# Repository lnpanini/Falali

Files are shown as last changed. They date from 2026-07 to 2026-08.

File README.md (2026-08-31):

# Falali — a 30.007 project

An AMR-style **under-ride platform** that drives beneath a textile trolley, uses upward-facing
time-of-flight sensors to confirm it is under the trolley and centred, **clamps** onto the
underside, and then moves the trolley. ESP32-S3 firmware, hardware and documentation.

This is also the whole-project home for **Falali — One AMR Fits All** (SUTD 30.007 Engineering
Design Innovation, Group 10): a low-profile autonomous mobile robot that moves existing fabric
trolleys in a textile factory by driving *underneath* them, clamping on, and transporting them —
no changes to the trolleys or the factory floor.

- **Controller:** ESP32-S3-WROOM-1 **N16R8** (16 MB flash, 8 MB octal PSRAM)
- **No** LiDAR, camera, ROS 2, SLAM, or mapping.

> **Hardware documentation lives in [`docs/hardware/`](docs/hardware/)** — power-up runbook,
> component list, per-connector pinouts for all three PCBs (extracted from the KiCad netlists, not
> inferred), and a fabrication/repair guide. [`docs/hardware-architecture.md`](docs/hardware-architecture.md)
> is the older companion and is partly superseded by it. The pin table further down this README is
> the *pre-PCB design intent* and does **not** match the fabricated board.

Full design: [`docs/superpowers/specs/2026-07-06-falali-esp32-docking-design.md`](docs/superpowers/specs/2026-07-06-falali-esp32-docking-design.md).

## Results against requirements

| Requirement | Target | Result |
|---|---|---|
| Fit under trolley clearance | ≤ 200 mm | **167 mm**, validated on the physical chassis |
| Move loaded trolley | ≥ 100 kg | **Passed — load moved with two people standing on top** |
| Clamp holding force | ≥ 300 N | Weakest-link analysis: clamp capacity 403 N (SF 1.34×) |
| Clamp vertical reach | ≥ 200 mm | Met |
| Docking time | ≤ 1 min | Under 60 s in testing |
| Worst-case castor misalignment | All 4 orientations | Moves under all |

Derivations, test protocols and data: [`docs/pdr-falali-amr.pdf`](docs/pdr-falali-amr.pdf)
(Preliminary Design Review deck, 11 Aug 2026).

## Delivered system

```
ESP-BASE (Wheel Drive PCB)                  ESP-ARM (Arm Subsystem PCB)
docking state machine                       arm axes X/Y, flipper servos, clamp
mecanum mixing, 4× corner ToF centring   ⇄  limit switches, homing
clamp handoff                             ESP-NOW over Wi-Fi (channel 1)

operator: BLE gamepad ([bench_ble/](bench_ble/))
```

Commercial AMRs don't fit this job: platform AMRs are too tall to get under the trolleys, tow
tractors need turning space, side-docking systems need the trolley modified. The answer is
**under-entry capture**: fit under the ≤200 mm clearance, strafe beneath an existing trolley with
mecanum drive, confirm centring sensor-only, clamp and carry.

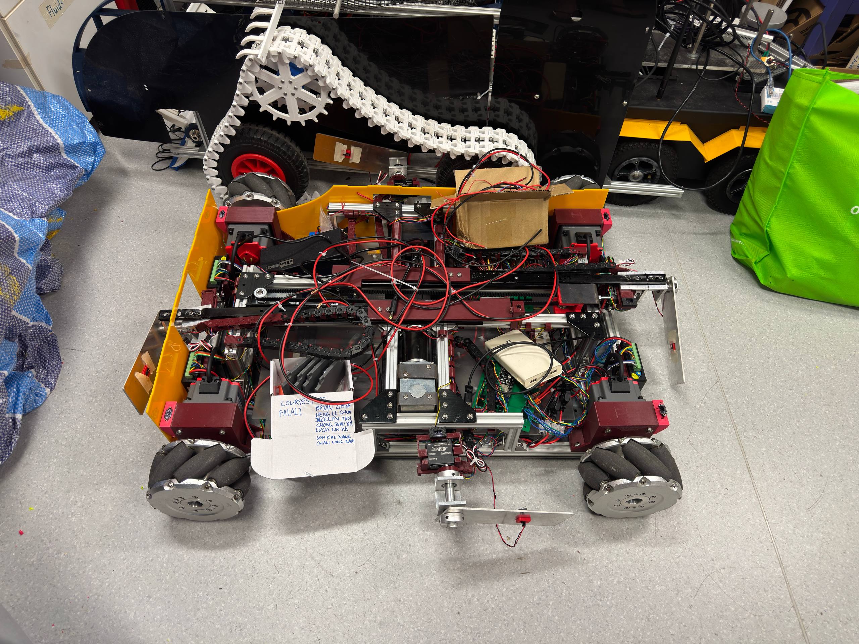
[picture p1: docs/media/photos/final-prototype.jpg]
Falali final prototype


## Safety principle

**The clamp must not engage unless the alignment logic CONFIRMS the platform is centred.** Limit
switches only confirm clamp *travel*; they never authorise clamping. `SafetyMonitor` is the single
gate (`confirmed && no faults && !E-stop`), and the docking state machine reaches the clamp handoff
only after a sustained `CONFIRM`. The clamp/arm mechanism itself is an **external subsystem** that
plugs in at the `IClamp` port.

## Architecture — hexagonal (ports & adapters)

```
lib/ports      pure C++ interfaces + shared types (no Arduino)
lib/domain     the hand-written core:  CornerEdgeDetector · DeadReckonOdometry · SafetyMonitor · DockingStateMachine
lib/drive      MecanumDrive (mixes body-frame vx/vy/omega -> 4 wheels)
lib/fakes      desktop test doubles for every port
lib/hal_esp32  Arduino adapters over popular libraries
include/       config.h (tunables) · pins.h (GPIO map)
src/main.cpp   composition root: builds adapters, wires domain, runs the loop
test/          host unit tests (Unity)
```

Dependency rule: **domain → ports** only; **adapters → ports**; **main → everything**. The domain
never includes Arduino, so it compiles and tests on a laptop. Commodity work uses popular libraries
(`pololu/VL53L0X`, `Bounce2`, `ArduinoJson`, `SerialCommands`, ESP32 `LEDC`); only the docking
sequence, corner edge detection, odometry, and safety logic are hand-written — and that is the part
under test.

**Alignment method:** with a solid trolley board and 4 corner ToF sensors, docking is a deterministic
geometric sequence — `APPROACH → ORIENT` (rotate until both front corners see the edge) `→ CENTER_X`
(odometry-centre between near/far edges) `→ CENTER_Y` (same, strafing) `→ CONFIRM → clamp handoff`.
Centring uses dead-reckoning odometry; driving to the midpoint between two edge events makes it robust
to calibration error.

**ToF wiring, both ESPs:** all four corner sensors keep their factory address `0x29` and are brought
up one at a time via **XSHUT re-addressing** — `Vl53l0xArray` on the base, `TofSensorArray` in
`arm/`. An earlier design multiplexed them through the PCA9548A breakout in
[`KiCad/PCA9548A Breakout/`](KiCad/PCA9548A%20Breakout/); final firmware uses no mux, and the
breakout is kept as history of that era.

## Build, test, flash

```bash
# Host unit tests of the pure core — no hardware needed:
pio test -e native

# Compile / upload the firmware (fetches lib_deps):
pio run -e esp32s3
pio run -e esp32s3 -t upload
pio device monitor -b 115200
```

Arm subsystem firmware has its own project: [`arm/`](arm/README.md).

## Operator interface — Xbox gamepad over BLE

**The robot is driven from a gamepad, not a serial console.** `bench_ble/` runs
Bluepad32, which owns stdin: `Console` is output-only and `Serial` is never
`begin()`-ed, so **typed commands cannot reach the firmware.** Every operator
control is a gamepad button. See [`docs/gotchas.md`](docs/gotchas.md) §6.

The base prints status to the console as it runs; that is one-way.

> A `DOCK`/`ABORT`/`UNCLAMP`/`STATUS` serial protocol was designed and the
> parser written, but it never ran on hardware — see **Project history** below.

## Pin map — ESP32-S3-N16R8

> ## 🛑 The table below is WRONG. Do not wire or flash from it.
>
> It is the **pre-PCB design intent** and does not match the fabricated board. On the real board
> GPIO4–7 are the **ToF XSHUT** lines, not wheel SV, and GPIO38/39 are **motor brake** lines, not
> I²C. Using this map would drive the I²C bus as motor enables.
>
> **The real map is [`include/pins.h`](include/pins.h)**, extracted from the KiCad netlist, with
> per-connector pinouts in [`docs/hardware/boards.md`](docs/hardware/boards.md).
>
> Kept here only because it is referenced by older notes. It should be deleted.

Reserved on the N16R8: **GPIO26–37** (flash + octal PSRAM) and **GPIO19/20** (USB-CDC).

| Group | Signals | GPIO |
|---|---|---|
| Wheel speed (SV, PWM) | FL/FR/RL/RR | 4, 5, 6, 7 |
| Wheel direction (F/R) | FL/FR/RL/RR | 15, 16, 17, 18 |
| Wheel enable / brake (ganged) | EN / BRK | 8 / 9 |
| Clamp (BTS7960) | RPWM / LPWM / EN | 11 / 12 / 13 |
| Clamp current sense (ADC1) | IS close / open | 1 / 2 |
| Limit switches | open / closed | 14 / 21 |
| ToF I²C | SDA / SCL | 38 / 39 |

## Hardware bring-up checklist (before trusting it under a trolley)

These adapters were validated on the assembled robot over the 2026 term. Kept as
a bring-up order for a rebuild, or after a board respin:

1. **PWM API** — a `PwmPin` shim supports Arduino-ESP32 core 2.x *and* 3.x automatically.
2. **BLD120A polarities** — `F/R` forward sense, and active-low `EN`/`BRK` (`Bld120aMotor.h`). There
   is no `ALARM`: the driver has no such terminal, only a front-panel LED.
3. **Mecanum + orient signs** — confirm forward / strafe / yaw directions (`MecanumDrive.cpp`) and the
   `ORIENT` rotate-direction sign in `DockingStateMachine.cpp` (rotate toward the lagging corner).
4. **ToF corners** — FL/FR/RL/RR on their XSHUT pins (`pins::kTofXSHUT`; `Vl53l0xArray` is the
   default backend since the mux approach was retired); set the board
   **height band** (`makeCornerConfig`).
5. **Odometry calibration** — measure `max_lin_mm_s` / `max_ang_rad_s` (`makeOdometryCal`); tune the
   centring tolerance/offsets in `makeDockConfig`.
6. **Per-wheel current sense** — calibrate `cfg::kWheelStallAmps` under a loaded trolley. Note the
   ACS758 outputs are **not currently wired** to J9/J12/J14/J17, so this reads nothing until they are
   ([`docs/hardware/components.md`](docs/hardware/components.md) §4). The clamp is on the *arm* board,
   not this one.
7. **Dry-run the alignment** and watch the JSON telemetry (`corners`, `x_mm`, `y_mm`, `confirmed`). The
   clamp/arm subsystem is external and validated separately at the `IClamp` handoff.

## Custom PCBs

Connector-level references for all boards (every pin extracted from the KiCad netlists):
[`docs/hardware/boards.md`](docs/hardware/boards.md).

| Board | Size | KiCad project | Job |
|---|---|---|---|
| **Wheel Drive PCB** | 130 × 105 mm | [`KiCad/Wheel Drive PCB/`](KiCad/Wheel%20Drive%20PCB/) | base ESP + 4 motor-driver adapters + all base sensors |
| **Driver PCB** ×4 | 42.8 × 33.8 mm | [`KiCad/Driver PCB/`](KiCad/Driver%20PCB/) | 3.3 V → open-collector adapter, one per motor |
| **Arm Subsystem PCB** | 110 × 110 mm | [`KiCad/Arm Subsystem PCB/`](KiCad/Arm%20Subsystem%20PCB/) | arm ESP + 2 H-bridges + servos + 8 limit switches |
| PCA9548A breakout | — | [`KiCad/PCA9548A Breakout/`](KiCad/PCA9548A%20Breakout/) | I²C mux — **historical**, see ToF note above |

JLCPCB fab outputs ship with each project (`fab-output/` folders; the Arm board's zip is in its
folder). Board designs by Kai Xiang & Heng Li (arm/wheel sensor side) and Bryan Lim (base).

## Demos

| | |
|---|---|
| <video src="docs/media/videos/load-test-100kg.mp4" controls width="320"> | **Load test** — ≥100 kg requirement load, two people on top |
| <video src="docs/media/videos/wheel-subsystem-driving.mp4" controls width="320"> | Mecanum base driving and strafing |
| <video src="docs/media/videos/arm-subsystem-demo.mp4" controls width="320"> | Arm extension / flipper / release sequence |
| <video src="docs/media/videos/clamped-on-trolley.mp4" controls width="320"> | Clamped onto a trolley |

*(GitHub renders `<video>` tags in markdown; if your viewer doesn't, open the files under
[`docs/media/videos/`](docs/media/videos/).)*

<details>
<summary>All clips kept in the repo</summary>

| File | What it shows |
|---|---|
| [`trolley-carry-demo.mp4`](docs/media/videos/trolley-carry-demo.mp4) | full trolley-carry run (1:49) |
| [`clamping-on-sequence.mp4`](docs/media/videos/clamping-on-sequence.mp4) | clamp engaging under the trolley (0:56) |
| [`rail-strength-test.mp4`](docs/media/videos/rail-strength-test.mp4) | rail strength durability test (0:29) |
| [`img-3340.mp4`](docs/media/videos/img-3340.mp4) | bench footage (0:51) |
| [`img-3350.mp4`](docs/media/videos/img-3350.mp4) | bench footage (0:43) |
| [`video-2026-07-13.mp4`](docs/media/videos/video-2026-07-13.mp4) | mid-build progress clip (0:16) |
| [`video-2026-07-17.mp4`](docs/media/videos/video-2026-07-17.mp4) | mid-build progress clip (0:10) |
| [`clip-20260707.mp4`](docs/media/videos/clip-20260707.mp4) | early drive test (0:05) |

</details>

### Function diagrams

| System flow | Arm subsystem |
|---|---|
| System flow function diagram | Arm subsystem function diagram |

*(SVGs render inline above; click through for the higher-resolution PNGs.)*

<details>
<summary>More photos</summary>

| | | |
|---|---|---|
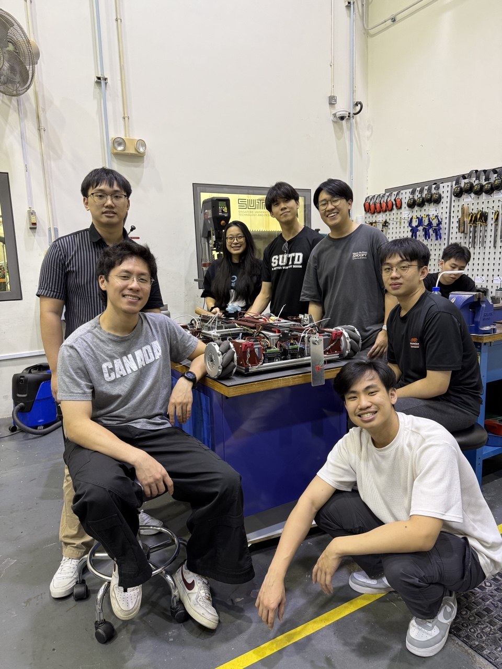
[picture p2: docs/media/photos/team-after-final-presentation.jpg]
Team after final presentation
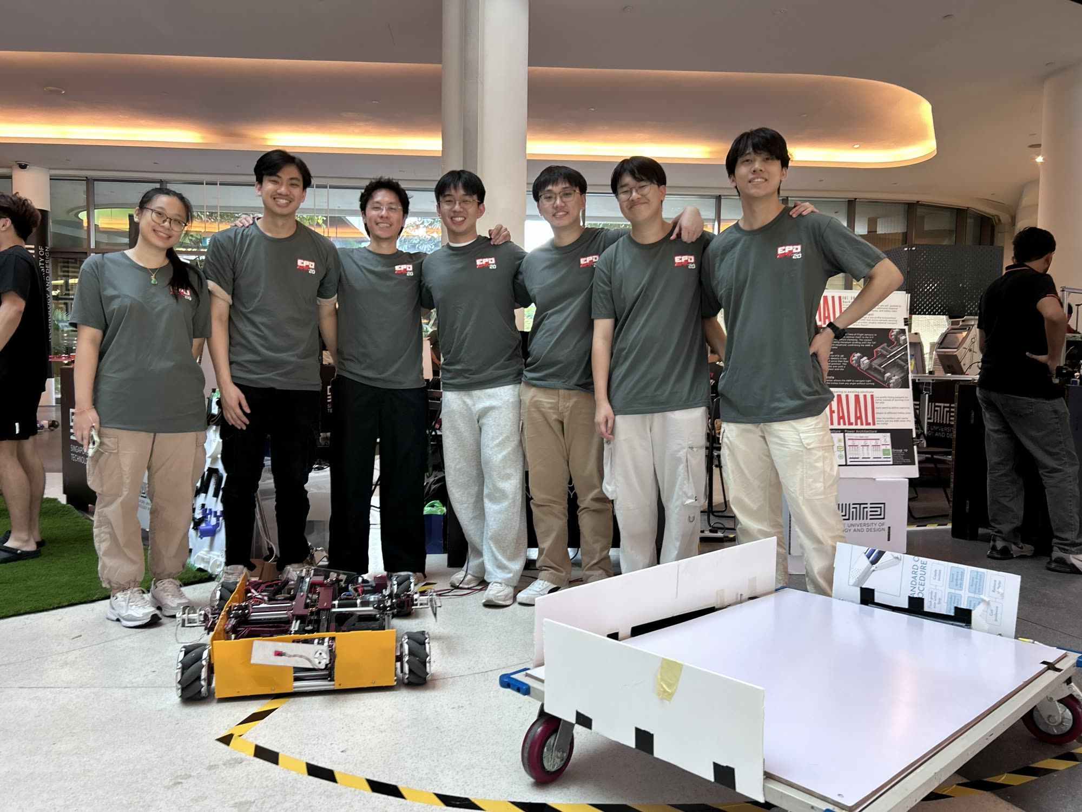
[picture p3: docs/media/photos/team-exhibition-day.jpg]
Exhibition day
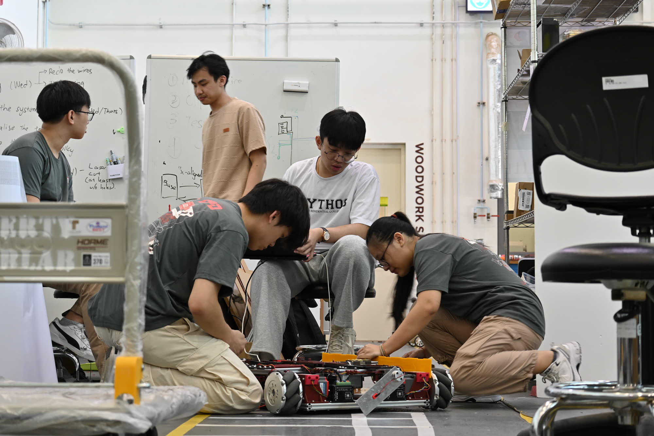
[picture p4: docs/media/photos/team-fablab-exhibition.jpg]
Fablab exhibition
|  |  |  |
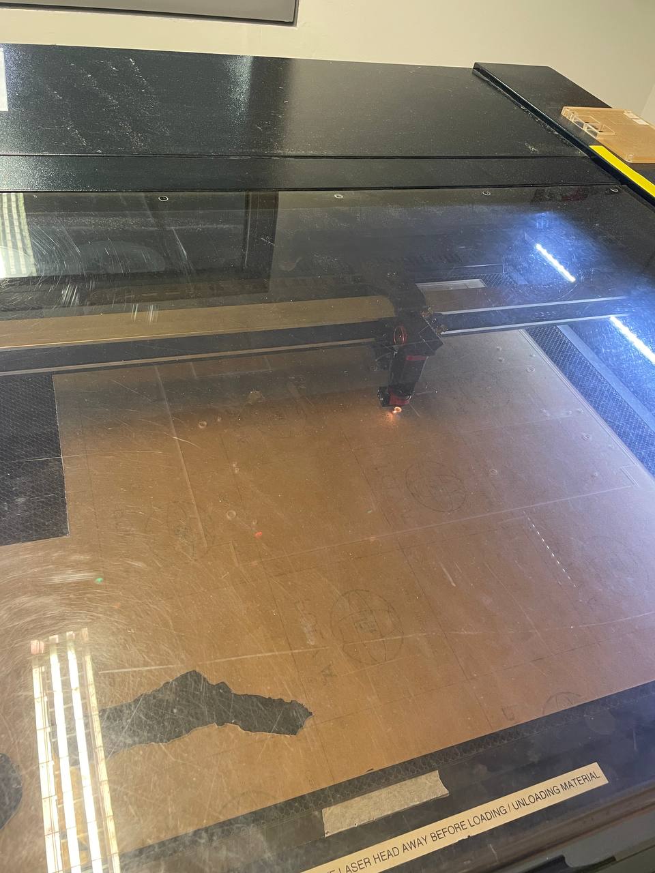
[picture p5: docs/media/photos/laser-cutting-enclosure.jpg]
Laser cutting the enclosure
|  | | |

All photos: [`docs/media/photos/`](docs/media/photos/).
</details>

## Team — Group 10

| Member | Focus areas |
|---|---|
| Chan Long Nam | mechanical structure & clamping system |
| Chong Shao Yih | chassis & integration |
| [Chua Heng Li](https://github.com/chuahengli) | electronics: arm-subsystem & wheel-drive PCBs, power wiring, arm firmware |
| Jacelyn Tan | systems analysis & testing |
| Lim Nguyen Ping, Bryan | drive firmware, sensing & base architecture (this repo) |
| Lucas Lim Kong Keong | clamping mechanism & materials |
| Soh Kai Siang | power distribution & wiring; co-author of arm firmware |

*Rows are initial attributions — each member, feel free to refine your own.*

## Repository map

| Path | What it is |
|---|---|
| [`src/`](src/README.md) | firmware entry + bench bring-up sketches |
| [`lib/`](lib/README.md) | hexagonal core: ports, domain, drive, fakes, ESP32 adapters |
| [`include/`](include/config.h) | tunables (`config.h`) and GPIO map (`pins.h`) |
| [`test/`](test/README.md) | host unit tests (Unity, `pio test -e native`) |
| [`arm/`](arm/README.md) | vendored arm-subsystem firmware (ESP-NOW slave) |
| [`KiCad/`](KiCad/README.md) | four custom board projects + fab outputs |
| [`bench_ble/`](bench_ble/README.md) | BLE-gamepad bench firmware |
| [`tools/`](tools/README.md) | PCB production test |
| [`docs/`](docs/) | specs, gotchas, hardware references, runbooks, session history, media |

## Project history — what was tried and dropped

Kept because knowing what was *attempted* saves repeating it. None of the below
is part of the delivered machine.

| Abandoned | What it was | Why it went |
|---|---|---|
| **AS5600 wheel encoders** | four magnetic encoders, one per wheel, for closed-loop speed | Never worked on the fabricated board: pin 1 of every 1×04 encoder header is unconnected, and all four parts share address `0x36` on a commoned bus. The sensors and shaft magnets are **still physically mounted on the motors**, unwired and undriven. [`docs/gotchas.md`](docs/gotchas.md) §13 |
| **TCA9548A / PCA9548A I²C mux** | fitted to give the four encoders separate addresses | Went with the encoders. An external PCA9548-type mux overheated and failed with more than two AS5600 attached. The ToF sensors never needed it — they use XSHUT re-addressing. Board files kept at [`KiCad/PCA9548A Breakout/`](KiCad/PCA9548A%20Breakout/) |
| **Raspberry Pi 5 as main controller** | Pi 5 driving two ESP32s over USB serial, with a link watchdog | Never used. The delivered prototype runs on the two ESP32s alone, base ↔ arm over ESP-NOW. Design retained at [`docs/superpowers/specs/2026-08-04-rpi5-main-controller-design.md`](docs/superpowers/specs/2026-08-04-rpi5-main-controller-design.md) |
| **`DOCK`/`ABORT`/`UNCLAMP`/`STATUS` serial protocol** | text commands in, JSON telemetry out | The parser was written but Bluepad32 owns stdin, so it never ran. Operator control is the gamepad. [`docs/gotchas.md`](docs/gotchas.md) §6 |
| **Hardware E-stop input** | a GPIO for an emergency-stop button | Discussed, never implemented. The red mushroom button on the robot is wired as an **enable** for the 12 V arm rail — [`docs/hardware/startup.md`](docs/hardware/startup.md) §1 |
| **Base-board clamp driver** | BTS7960 clamp driven from the base ESP | Moved to the arm subsystem. The base pins remain `kNoPin` so the one-ESP firmware still compiles |

Code for the encoders, the mux and the Pi was **deleted on 2026-08-31** rather
than left to rot — `git log --diff-filter=D` recovers any of it. What was worth
keeping is the analysis of *why* each failed, which lives in
[`docs/gotchas.md`](docs/gotchas.md) and [`docs/hardware/`](docs/hardware/).

## Acknowledgements

- Course 30.007 Engineering Design Innovation, SUTD; reviewed by Prof. Bradley Camburn and Prof. Wai Lee Chan
- Firmware drafting and design-analysis support used AI tooling (Claude, Gemini), as disclosed in the PDR

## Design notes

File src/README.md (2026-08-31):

# src/ — firmware entry points & bench sketches

| File | What it is |
|---|---|
| `main.cpp` | the docking firmware — composition root: builds adapters, wires the hexagonal core, runs the loop |
| `bench_pcb_rl.cpp` | production-test firmware for the Wheel Drive PCB (`env:pcb_rl`); driven by [`tools/board_test.py`](../tools/board_test.py) |
| `i2c_scan.cpp`, `tof_scan.cpp` | bus utilities: scan the I²C bus, probe VL53L0X sensors |
| `pcb_identify.cpp` | identifies which PCB a DevKit is plugged into by probing its peripherals |
| `bench_mix.h` | mecanum body-frame → wheel mix, shared with the base firmware |

PlatformIO environments for all of these live in [`platformio.ini`](../platformio.ini).

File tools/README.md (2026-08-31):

# tools/ — bench & production tooling

| Tool | What it is |
|---|---|
| `board_test.py` | production test loop for manufactured Wheel Drive PCBs: runs `env:pcb_rl` against board after board, records results to CSV |
| `board_test_log.csv` | logged results from real board-test sessions |
| `golden_signature.json` | expected GPIO states extracted from the netlist — what a healthy board must match |

`magtune.py` (AS5600 magnet tuner), `find_pi.sh` and `pi_bootstrap.sh` were
removed 2026-08-31 with the encoders and the Raspberry Pi 5 plan they served.

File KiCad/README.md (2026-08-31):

# KiCad/ — custom PCB projects

Connector-level references for every board (extracted from these netlists):
[`docs/hardware/boards.md`](../docs/hardware/boards.md).

| Project | Size | Job |
|---|---|---|
| [`Wheel Drive PCB/`](Wheel%20Drive%20PCB/) | 130 × 105 mm | base ESP + 4× Driver PCB headers + all base sensors |
| [`Driver PCB/`](Driver%20PCB/) | 42.8 × 33.8 mm | 3.3 V → open-collector adapter for the BLD-120A, one per motor (need 4) |
| [`Arm Subsystem PCB/`](Arm%20Subsystem%20PCB/) | 110 × 110 mm | arm ESP + 2 BTS7960 H-bridges + servo power + 8 limit-switch headers |
| [`PCA9548A Breakout/`](PCA9548A%20Breakout/) | — | 8-ch I²C mux — historical; final firmware uses XSHUT re-addressing instead |

## Board renders

Every board carries schematic / PCB-layout / 3D-view images next to its sources
(the Driver PCB keeps its design-history set under `preview/`). Thumbnails below
are embedded — click any image for the full-resolution file:

| Board | Schematic | PCB layout | 3D view |
|---|---|---|---|
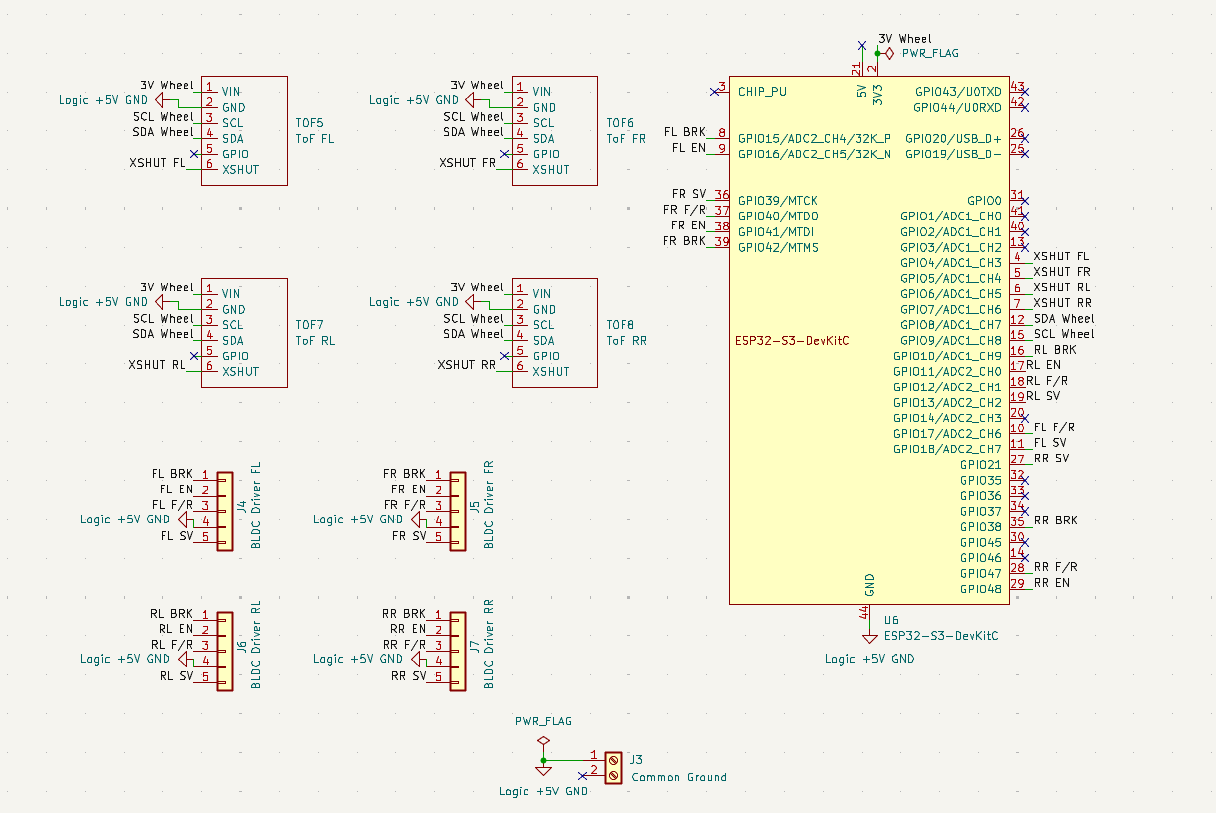
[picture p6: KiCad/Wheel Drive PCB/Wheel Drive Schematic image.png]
Wheel Drive schematic
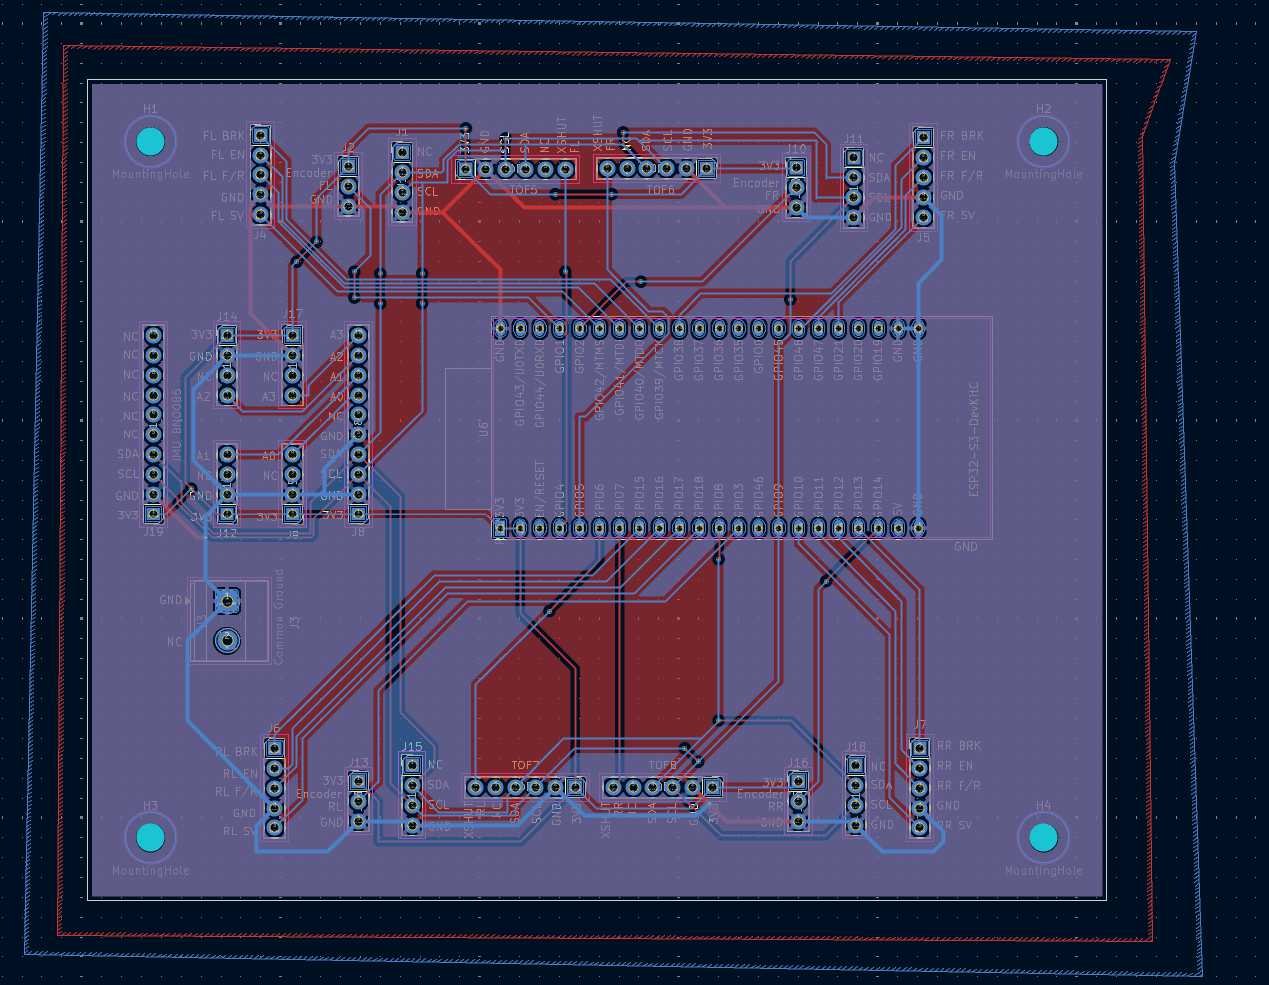
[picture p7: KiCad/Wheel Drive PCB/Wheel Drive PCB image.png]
Wheel Drive PCB layout
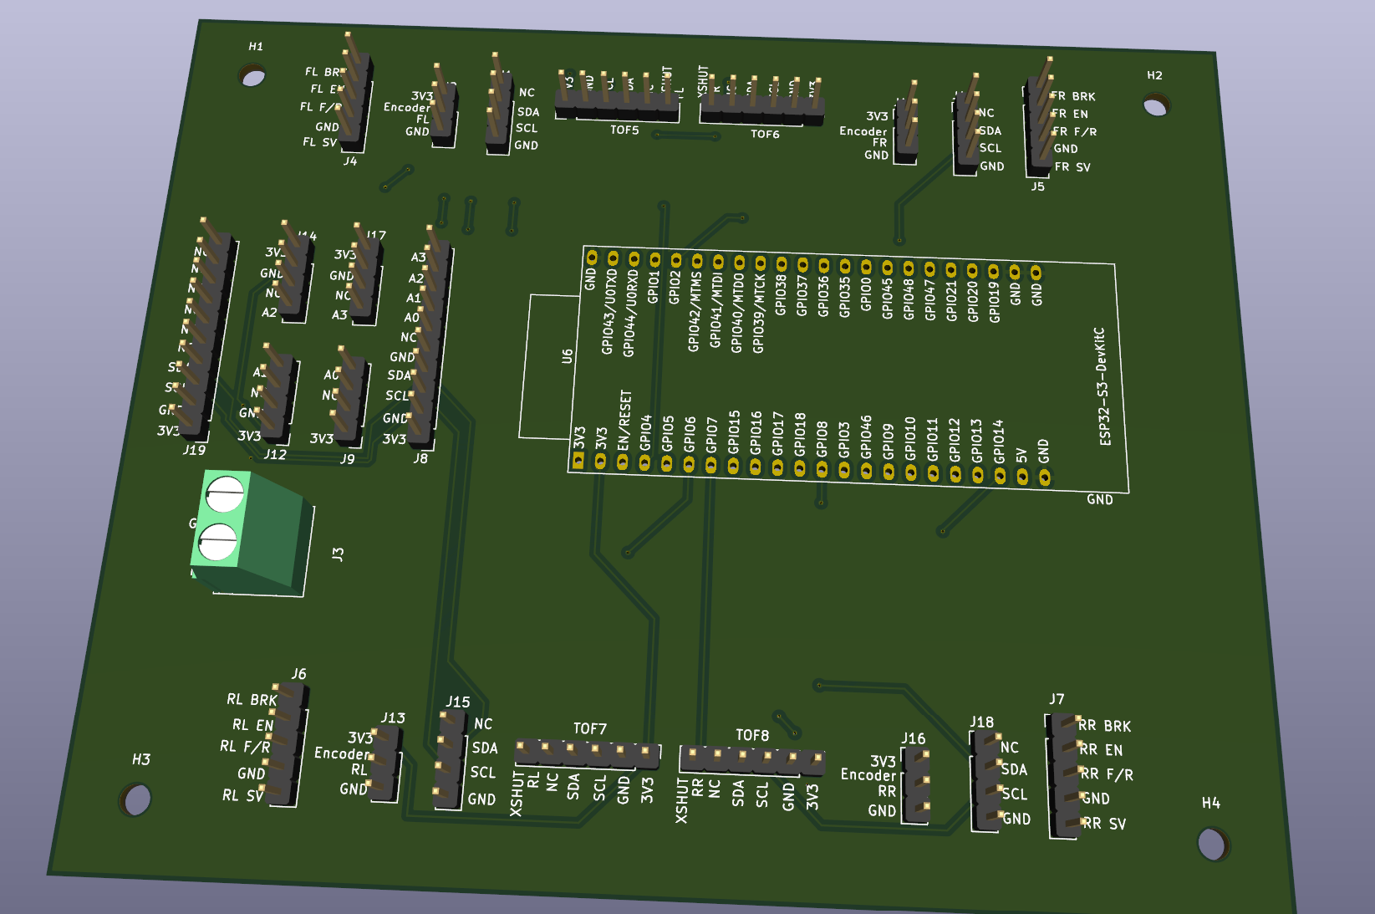
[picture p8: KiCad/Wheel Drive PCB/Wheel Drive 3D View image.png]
Wheel Drive 3D view
| Wheel Drive PCB |  |  |  |
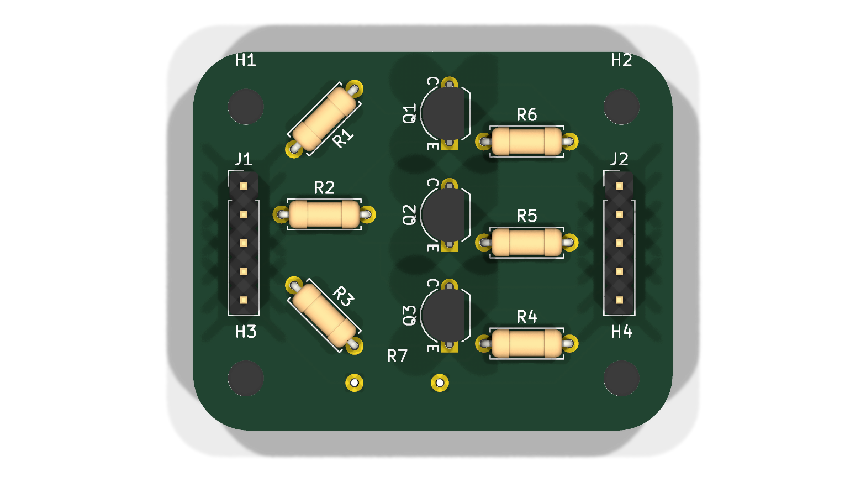
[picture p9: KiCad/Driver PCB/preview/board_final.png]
Driver PCB final
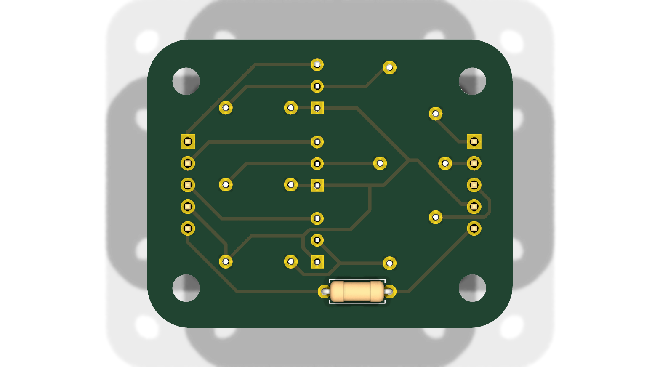
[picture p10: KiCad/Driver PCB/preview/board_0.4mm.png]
Driver PCB 0.4 mm
| Driver PCB ×4 | — |  |  |
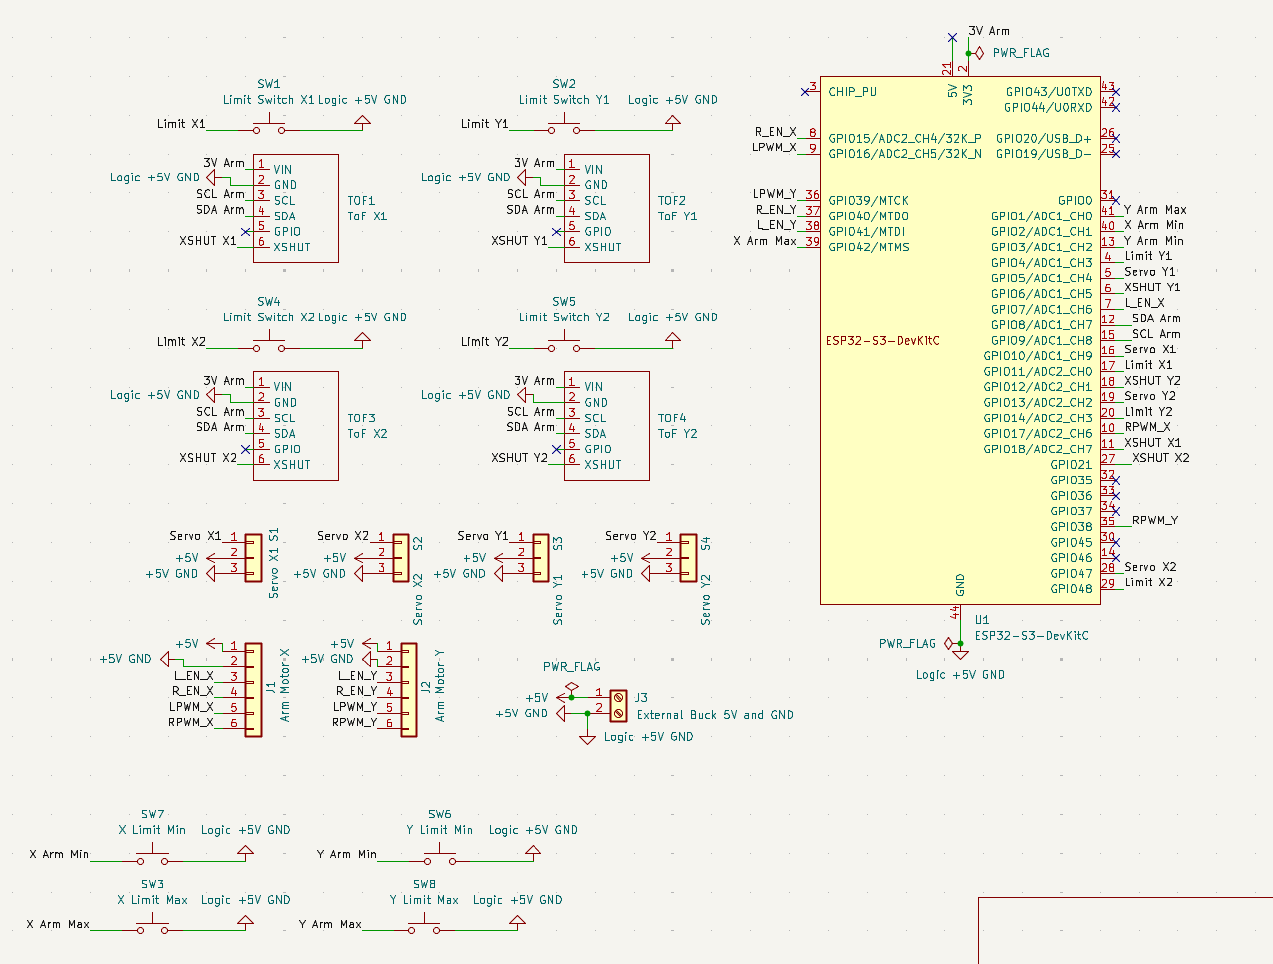
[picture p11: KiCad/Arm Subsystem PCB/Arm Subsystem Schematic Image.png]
Arm Subsystem schematic
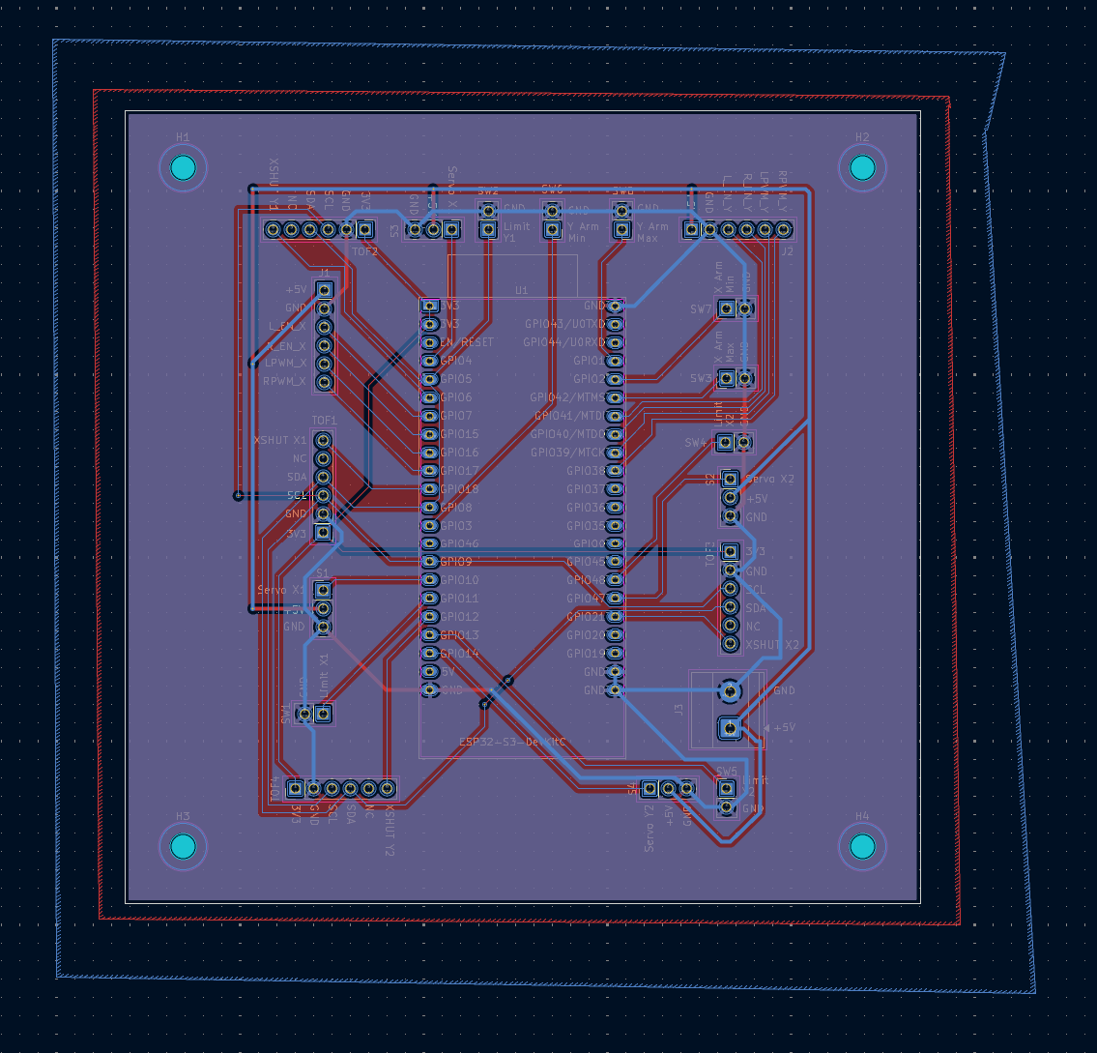
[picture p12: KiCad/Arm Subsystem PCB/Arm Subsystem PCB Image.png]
Arm Subsystem PCB layout
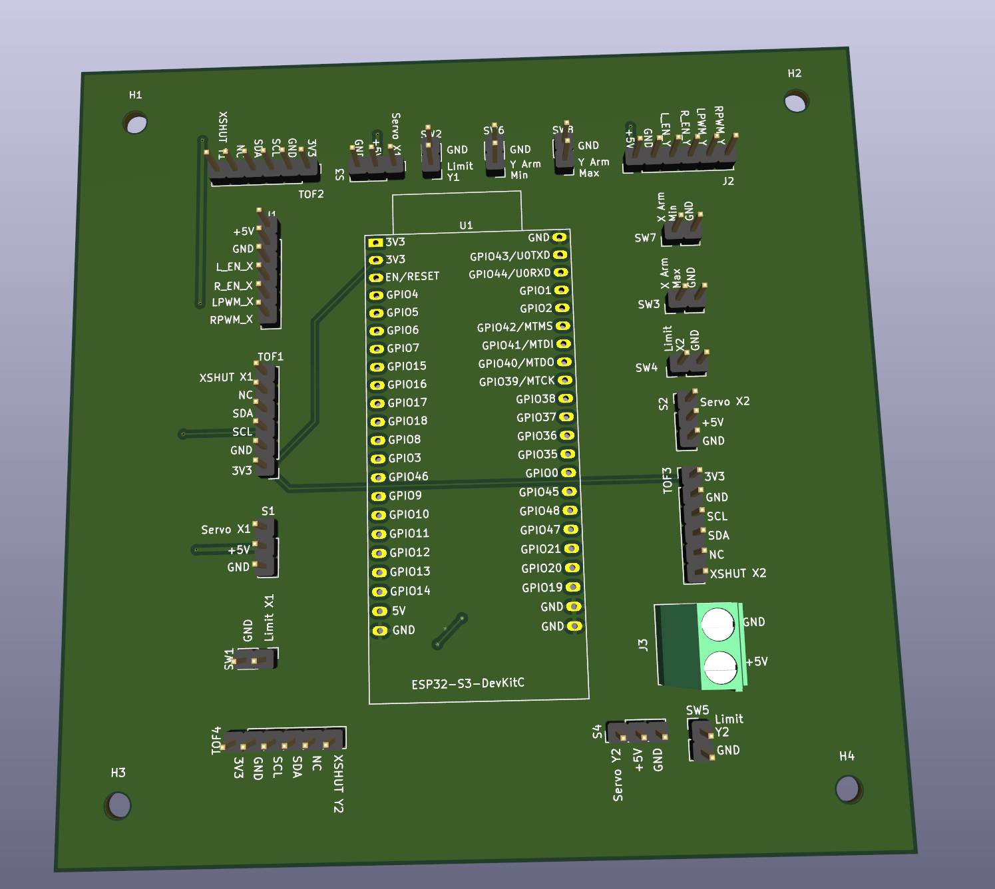
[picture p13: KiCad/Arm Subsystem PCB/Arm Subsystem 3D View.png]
Arm Subsystem 3D view
| Arm Subsystem PCB |  |  |  |
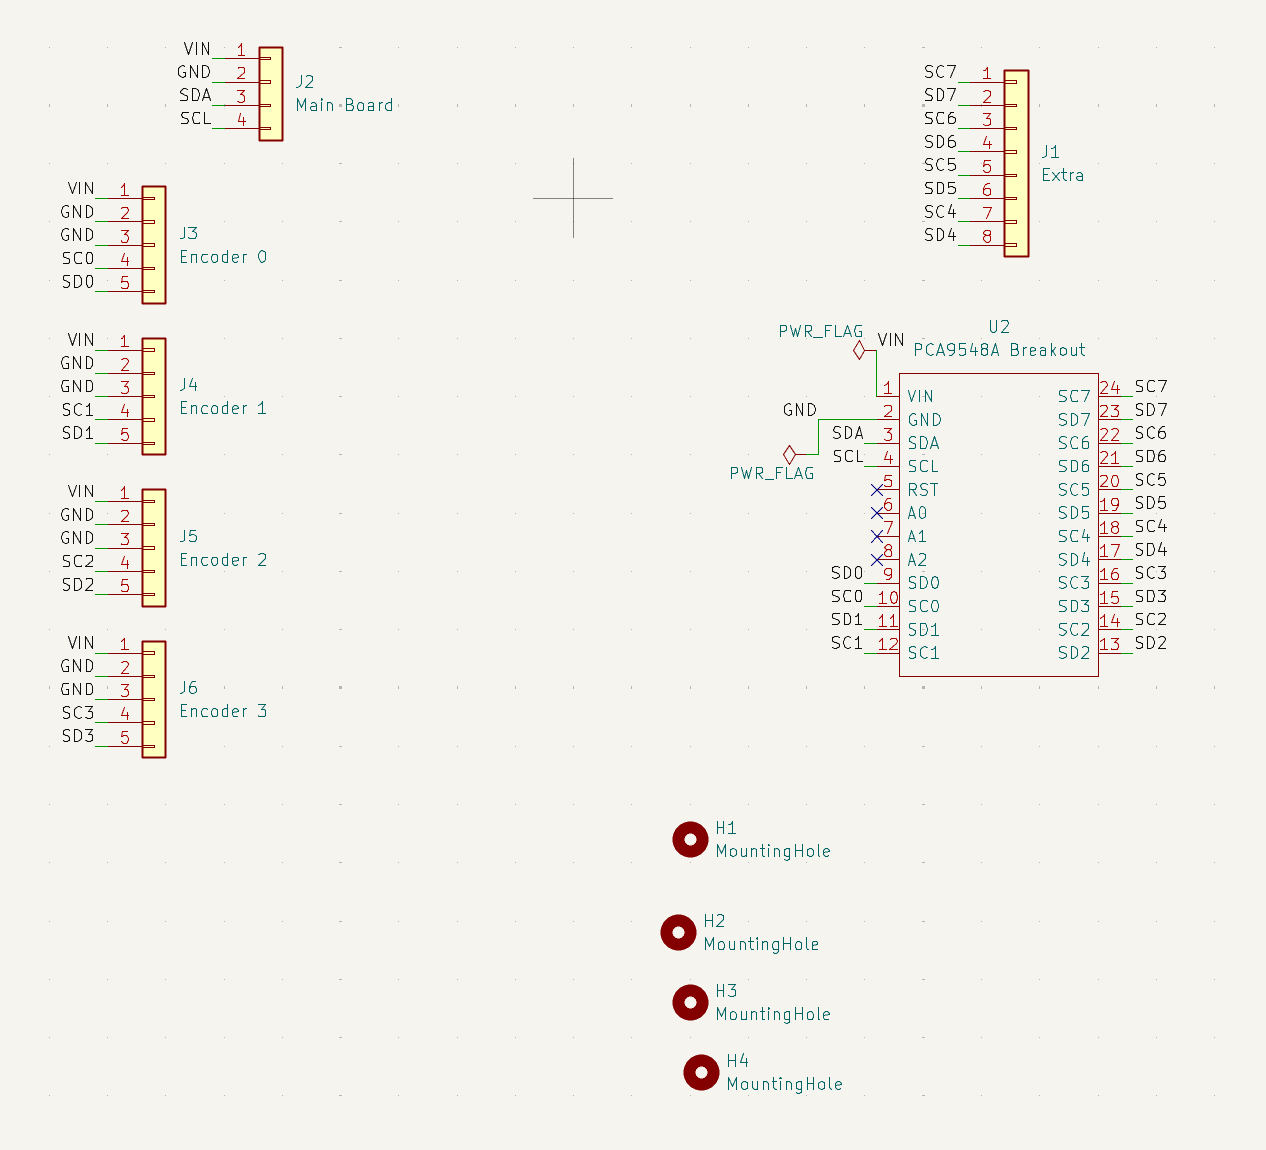
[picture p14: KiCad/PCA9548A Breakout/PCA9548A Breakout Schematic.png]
PCA9548A schematic
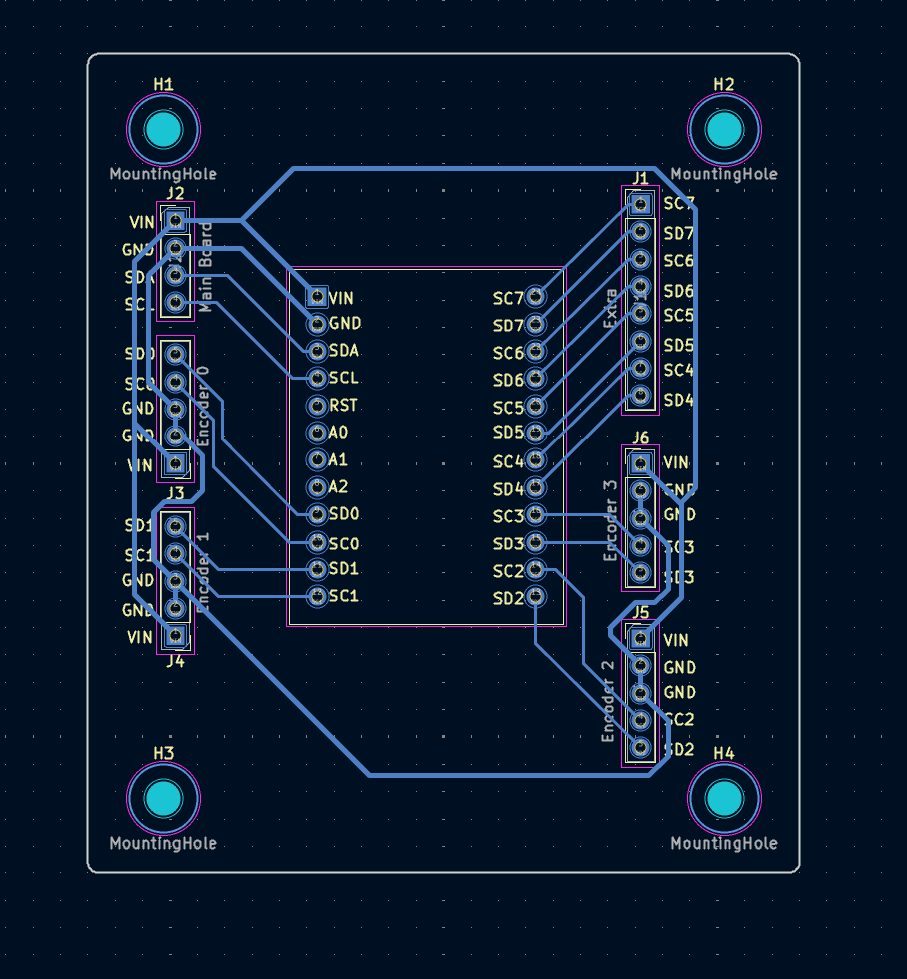
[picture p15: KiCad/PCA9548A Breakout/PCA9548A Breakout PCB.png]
PCA9548A PCB layout
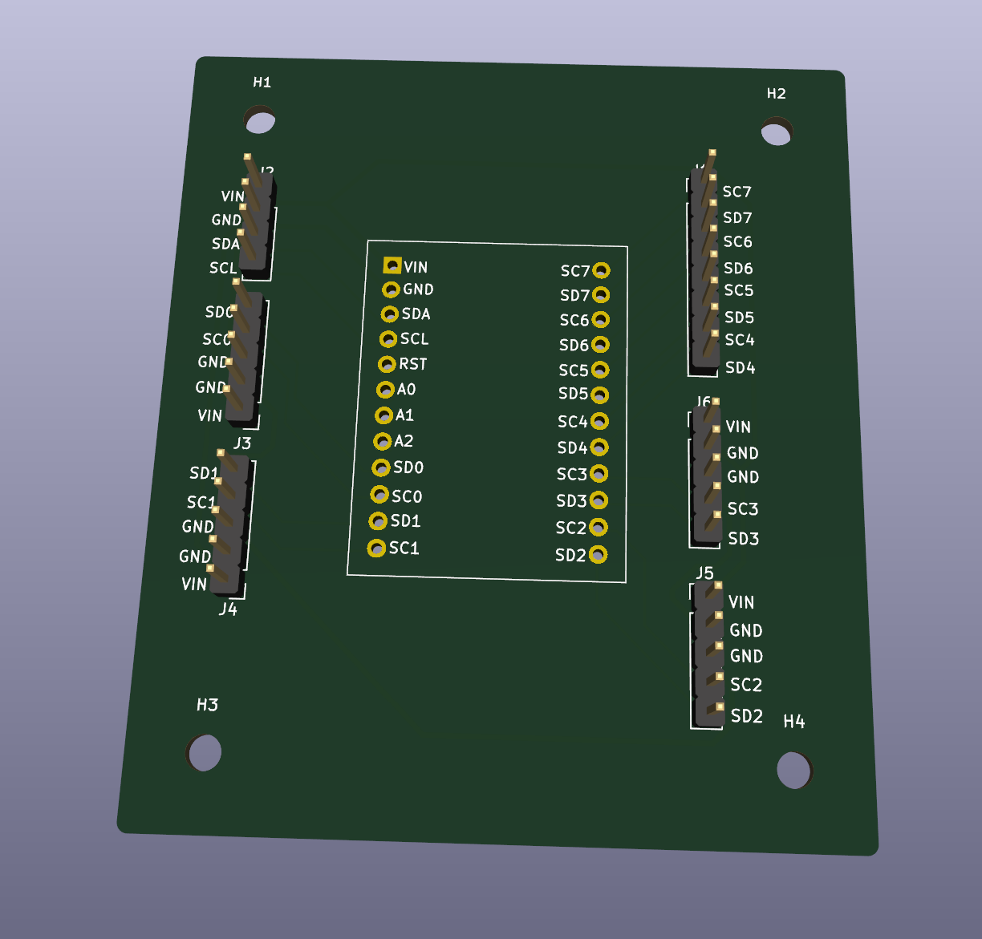
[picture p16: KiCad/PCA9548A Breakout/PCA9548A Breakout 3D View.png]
PCA9548A 3D view
| PCA9548A breakout |  |  |  |

More Driver PCB renders — design history (placement, routing progress, copper
layers; click to open):

| | | |
|---|---|---|
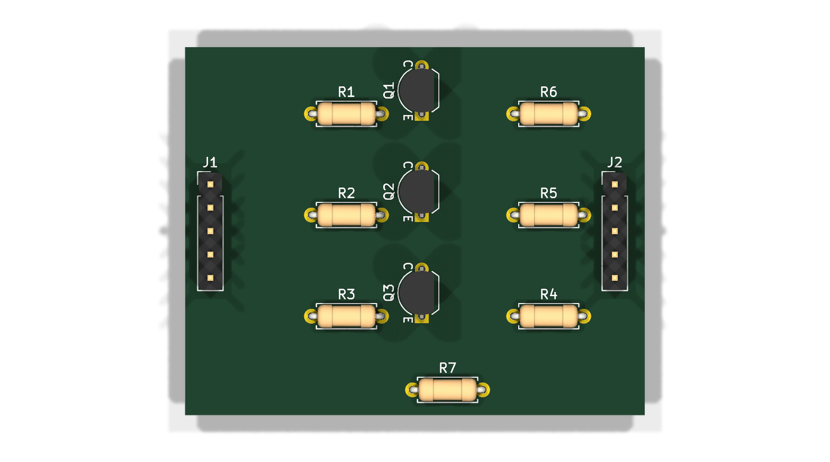
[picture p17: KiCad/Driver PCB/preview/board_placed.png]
Placement
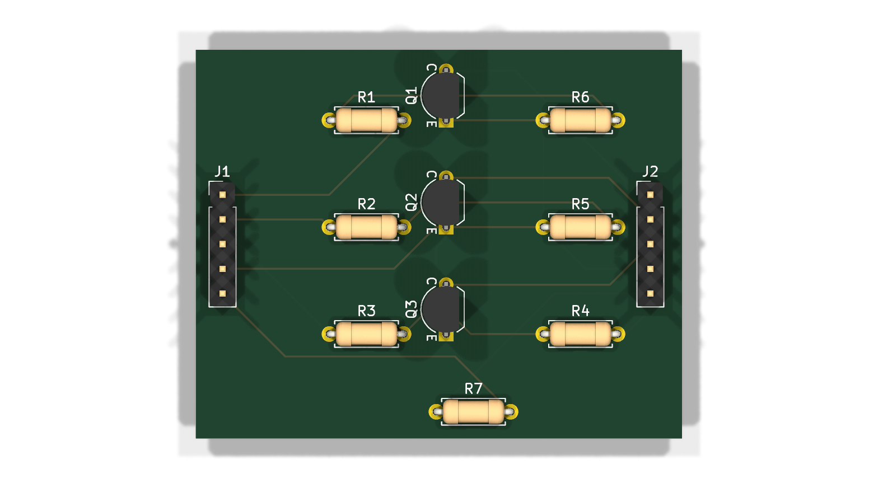
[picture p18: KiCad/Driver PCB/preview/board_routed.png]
Routing progress
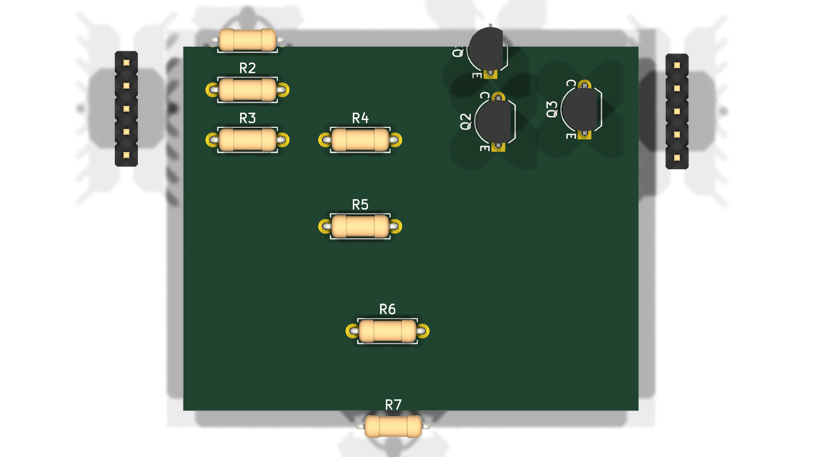
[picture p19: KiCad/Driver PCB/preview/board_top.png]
Top copper
|  |  |  |
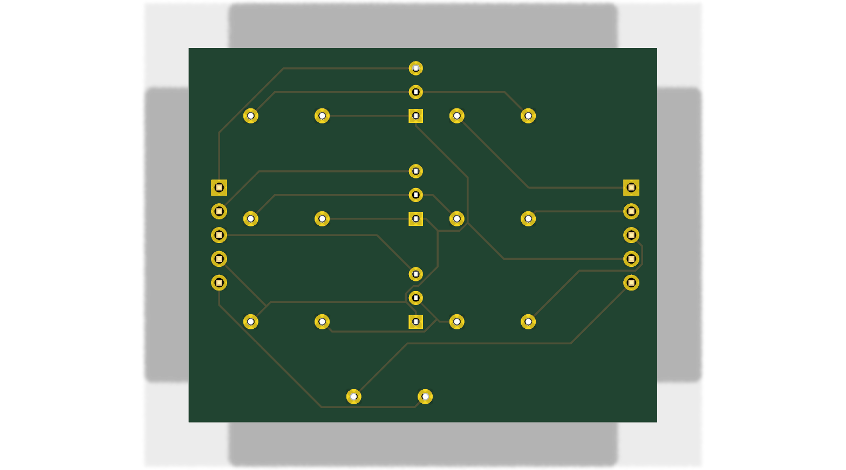
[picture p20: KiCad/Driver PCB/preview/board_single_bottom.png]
Single bottom
|  | Routed copper (SVG) | Bottom copper (SVG) |

Connector-level pin tables live in
[`docs/hardware/boards.md`](../docs/hardware/boards.md); these renders are the
visual companion to that reference.

Each project folder carries the KiCad sources (`.kicad_pro/.kicad_sch/.kicad_pcb`),
the extracted netlist (`.net`), schematic/PCB/3D renders as PNG, and JLCPCB fab
outputs (`fab-output/`; the Arm board's are zipped). Board designs: Kai Xiang &
Heng Li (Arm Subsystem, PCA9548A breakout), Bryan Lim (Wheel Drive, Driver).

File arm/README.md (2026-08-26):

# ESP-ARM — arm subsystem firmware

Runs on the **arm ESP32-S3**. Receives commands from the base over ESP-NOW and
drives the two travel axes, the four flipper servos and the clamp signal.

## Authorship

**Written by Kai Xiang and Heng Li, EPD Batch of 2028.**

Vendored into this repository from
[`sks0826/Arm_code`](https://github.com/sks0826/Arm_code) at commit
`ca81eef096dc06a8c228da2e69a983bfa2abafc4`, plus the local fixes recorded in
[`LOCAL-CHANGES.md`](LOCAL-CHANGES.md).

It was a git submodule until 2026-08-14. That was changed because a submodule is
a poor fit for a handover: the fixes below live only in this working tree, so
anyone cloning Falali would have got firmware that does not talk to the base,
with nothing on screen to say why. Vendoring makes one clone give one working
pair of boards.

A predecessor exists — `chuahengli/30.007-EDI-ESP32-Arm-System`, which spoke
single-character commands over a three-wire UART. **It is superseded.** The base
no longer has a UART link and its GPIO1/2 are free. Do not flash it expecting the
gamepad to reach the arm.

## Building and flashing

```bash
cd arm && pio run -e esp32s3 -t upload
```

Its serial console is **UART0 on GPIO43/44 at 115200** — the DevKitC's `UART`
port, not the one marked `USB`. `platformio.ini` leaves `build_flags` empty, so
`ARDUINO_USB_CDC_ON_BOOT` defaults to 0 and no CDC object is linked into the
binary at all. Plugging into the native USB port gives a port that enumerates,
stays silent, and ignores everything typed at it.

## The interface the base depends on

Four commands over ESP-NOW, **WiFi channel 1**, plain text, NUL-terminated:

| command | effect |
|---|---|
| `grab` | extend X → flip X servos 170°→80° → retract X, then the same for Y |
| `release` | as `grab`, but servos return 80°→170° |
| `home_setup` | all four servos home, then retract X, then retract Y |
| `estop` | stop everything, reply `stopped` |

Replies: `done_grab`, `done_release`, `done_home`, `busy`, `stopped`,
`failed:<reason>`, `rejected:<reason>`.

**These strings are an interface.** The base sends exactly these; renaming one
breaks the pair silently, because an unrecognised command is answered
`rejected:unknown_command` and nothing moves.

The serial console carries a much larger command set (`xext`, `xret`, `yext`,
`yret`, `mstop`, `fx`, `fy`, `ex`, `ey`, `clamp`, `limit`, …). Since the
fall-through fix below, all of it is reachable over ESP-NOW too, which is how the
base's LT/RT + D-pad manual controls work.

## Before you change anything here

Read [`../docs/gotchas.md`](../docs/gotchas.md). Several behaviours in this
firmware are surprising in ways that cost days to rediscover — an out-of-range
ToF reading counting as "clear air", a receive buffer that holds exactly one
command, and extend checking a different limit switch from retract.

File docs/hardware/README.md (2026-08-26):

# Falali — hardware documentation

Handover documentation for **SOAR**. The firmware side is documented in
`docs/gotchas.md` and `docs/hardware-architecture.md`; this folder is the
hardware.

Falali is an ESP32-S3 under-ride docking AGV: a mecanum base that crabs
sideways under an 860 × 1260 mm trolley, aligns on four corner ToF sensors, and
hands off to an arm subsystem that clamps it.

---

## Start here

| If you want to… | Read |
|---|---|
| **Switch it on without breaking it** | [`startup.md`](startup.md) |
| Know what a part is, or what's worth salvaging | [`components.md`](components.md) |
| Find which GPIO a connector pin goes to | [`boards.md`](boards.md) |
| Order more boards, or change one | [`fabrication.md`](fabrication.md) |
| Avoid a trap that already cost someone days | [`../gotchas.md`](../gotchas.md) |

**If you read only one thing, read `startup.md` §1.** The big red mushroom
button is wired as an *enable*, not an emergency stop — pressing it turns the arm
rail **on**. That is the single most dangerous surprise in this machine.

---

## How these documents are written

Every claim carries a tag, because treating a good guess as a fact is how the
next person loses a day:

- **[VERIFIED]** — read from the KiCad netlist or firmware source, or measured on
  hardware, and quoted here. Build on it.
- **[OBSERVED]** — this happened on the robot and the evidence is quoted. The
  cause may still be open.
- **[HYPOTHESIS]** — a model that fits the evidence and has not been tested
  against an alternative. It may be wrong. Where one is load-bearing, the
  experiment that would kill it is written alongside.

Gaps are listed explicitly at the end of `startup.md` and `components.md` rather
than left silent, so an absence is never mistaken for a completed survey.

**The KiCad netlists are the authority for anything electrical.** `boards.md` was
built by parsing `*.net` directly, not by reading a rendered schematic. Where
`include/pins.h` or the older docs disagree with the netlist, the disagreement is
called out in place.

---

## What's in the repo

| Path | |
|---|---|
| `KiCad/Wheel Drive PCB/` | Base board — ESP, 4 driver outputs, all base sensors |
| `KiCad/Driver PCB/` | 3.3 V → open-collector adapter (**build 4**) |
| `KiCad/Arm Subsystem PCB/` | Arm board — by **Kai Xiang and Heng Li, EPD Batch of 2028** |
| `bench_ble/` | Base firmware — ESP-IDF + Bluepad32, gamepad, docking |
| `arm/` | Arm firmware — vendored, same authors |
| `lib/domain/` | Pure docking logic, 77 host tests |
| `include/pins.h` | Base GPIO map, netlist-derived |
| `docs/BLD-120-English-version.pdf`, `docs/SYS-BLD-120A-manual.pdf`, `docs/BLDC-BLD120A-bldc-motor-controller-specs.pdf` | Driver manuals. They **contradict each other**, and the BLD-120A-specific spec sheet is the tie-breaker — see `components.md` §2. The spec sheet is image-only; reading it needs `pdftoppm` (poppler) |
| `docs/hardware/img/motor-80-flange-spec-table.jpeg` | Motor datasheet — the source for every figure in `components.md` §2 |

---

## Known open items, carried over deliberately

These are recorded rather than quietly left. Full detail in `gotchas.md`.

| | Status |
|---|---|
| **X-axis extend does not stop at its limit switch** | Open. The netlist has now **eliminated the leading hypothesis** — SW3 *is* correctly wired to GPIO42. See `boards.md` §3 for what survives and the 30-second test that settles it |
| **Arm PCB servo headers are dead in firmware** | The board wires S1–S4 to GPIO; the firmware drives a PCA9685 over I²C that has no home on the board. `boards.md` §3 |
| **The red button is an enable, not an E-stop** | The 12 V rail sits on the switch's normally-open contact; the part has an unused NC contact. `startup.md` §1 |
| **The current sensors are not wired up** | Fitted inline on the motor negative, but their outputs go nowhere — so the base has **no drivetrain fault detection at all**. `components.md` §4 |
| **The ACC/DEC trim has never been checked** | A third, previously undocumented driver pot that ramps every speed change over **0.3–15 s**. Could invalidate the odometry and look exactly like stiction. `gotchas.md` §19 |
| **SV is driven at 3.3 V, spec is 5 V** | May be capping top speed at ~70 %. One level-shifted wheel would settle it. `components.md` §2 |
| **Battery is undocumented** | Custom-built: no chemistry, cell count, BMS rating or charge profile exists anywhere. `components.md` §1 |
| **Two custom KiCad libraries missing** | Boards can be re-ordered as-is, but not cleanly re-synced. `fabrication.md` §3 |
| **Encoders abandoned** | No wheel-speed feedback — but **the motors have unused hall sensors**, landing on the drivers' own screw terminals. `components.md` §2 |
| **Gearbox ratio is inherited, not verified** | Documented everywhere as 15:1; the purchase listing groups the motor as "ratio 10–18". The speed ceiling depends on it. `components.md` §2 |

---

## Credits

Base hardware, base firmware, docking logic and these documents: **Bryan**.
Arm Subsystem PCB and `arm/` firmware: **Kai Xiang and Heng Li, EPD Batch of
2028**.

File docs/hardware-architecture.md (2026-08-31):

# Falali — hardware architecture and parts list

**Last updated:** 2026-08-05. **Partially superseded 2026-08-16** — see below.
**Authoritative sources:** `Wheel Drive PCB.net` (Eeschema 9.0.6, 2026-08-05) for every
GPIO assignment; `docs/BLD-120-English-version.pdf` for driver behaviour; bench
measurements dated inline.

This document exists because the same facts kept getting re-derived from rendered
schematics and stale notes, and twice got derived wrong.

> ## ⚠️ Read `docs/hardware/` first
>
> As of **2026-08-16** the handover documentation lives in
> [`docs/hardware/`](hardware/), and it was built by parsing the KiCad netlists
> of **all three** boards directly:
>
> | | |
> |---|---|
> | [`hardware/startup.md`](hardware/startup.md) | power tree and power-up runbook — **none of this is in any KiCad file** |
> | [`hardware/components.md`](hardware/components.md) | parts, specs, and what is worth salvaging |
> | [`hardware/boards.md`](hardware/boards.md) | every connector pinout on all three boards, netlist-verified |
> | [`hardware/fabrication.md`](hardware/fabrication.md) | re-ordering, modifying and repairing the boards |
>
> **Where this file and `docs/hardware/` disagree, `docs/hardware/` is newer**
> and says which netlist line it came from. Sections below that have been
> superseded are marked inline. The GPIO tables in §2 were re-checked against the
> netlist on 2026-08-16 and are **correct** — it is the surrounding commentary
> that had drifted.

---

## 1. System topology

> **⚠️ This diagram is stale in two places.** Corrected version below it.

```
Raspberry Pi 5  ──USB──  ESP-BASE (Wheel Drive PCB)  ──  4× BLD-120A  ──  4× BLDC motor
   (brain)                 ESP32-S3-DevKitC-1 N16R8        (24 V)          (15:1 gearbox)
                                  │
                                  ├── 4× VL53L0X ToF         (XSHUT re-addressing)
                                  ├── 1× BNO085 IMU
                                  ├── 1× ADS1115 ← 4× ACS758LCB current sensors
                                  │
                                  └──UART1 (GPIO1/2)── ESP-ARM ── clamp + flippers

                                       4× AS5600 encoder  [REMOVED 2026-08-13]
```

**As actually built, 2026-08-16:**

```
  Xbox BLE gamepad
        │ (Bluepad32, BLE)
        ▼
  ESP-BASE (Wheel Drive PCB) ── J4–J7 ── 4× Driver PCB ── 4× BLD-120A ── 4× BLDC
  ESP32-S3-DevKitC-1 N16R8              (3V3→open-collector)   (24 V)   (15:1, 152 mm)
        │
        ├── 4× VL53L0X ToF     (XSHUT re-addressing, GPIO4-7)
        ├── 1× BNO085 IMU      (0x4A)
        ├── 1× ADS1115 (0x48)  ← 4× ACS758LCB current sensors
        │
        └── ESP-NOW, WiFi ch 1 ──► ESP-ARM (Arm Subsystem PCB)
                                     ├── 2× BTS7960 ── wormgear extension (12 V)
                                     ├── PCA9685 (0x40) ── 4× flipper servo (5 V)
                                     ├── 4× VL53L0X ToF  (0x30–0x33)
                                     └── 8× limit switch

  4× AS5600 encoder  [REMOVED 2026-08-13 — no wheel-speed feedback of any kind]
```

**Two corrections to the original diagram:**

1. **The base↔arm link is ESP-NOW, not UART on GPIO1/2.** The UART never passed
   a byte and was retired 2026-08-14 — §5 of this document already records
   this, the diagram was simply never updated.
2. **The Raspberry Pi 5 is not in the control loop.** The gamepad connects
   directly to the base ESP over BLE and the docking state machine runs on the
   base. The Pi-5-as-brain design (decision log, 2026-08-04) was superseded by
   the ESP32-S3-only prototype. **[VERIFIED — Bryan, 2026-08-31: no Raspberry Pi
   was ever used.]** The `pi/` tooling and the Pi setup runbook were deleted
   2026-08-31; the design spec is kept as a dated record.

The encoders never worked on the fabricated board and have been abandoned. There
is now **no wheel-speed feedback of any kind** — the only drivetrain fault signal
is per-wheel current (`cfg::kWheelStallAmps`).

See `docs/superpowers/specs/2026-08-04-rpi5-main-controller-design.md` for the
control split and the link watchdog.

---

## 2. GPIO map — ESP32-S3-DevKitC-1 **N16R8**

Extracted from the netlist. Mirrored in `include/pins.h`; that file is the code's
copy of this table.

### Wheel motors (index order FL, FR, RL, RR — matches `fal::Corner`)

| Signal | FL | FR | RL | RR |
|---|---|---|---|---|
| **SV** (speed, PWM) | 42 | 21 | 18 | 10 |
| **F/R** (direction) | 41 | 47 | 17 | 11 |
| **EN** (enable) | 40 | 48 | 16 | 12 |
| **BRK** (brake) | 39 | 38 | 15 | 13 |

**EN and BRK are per-wheel, not ganged.** The pre-PCB design assumed one shared
pair; the fabricated board gives each wheel its own. Independent shutdown is
strictly better, but `main.cpp` must pass each motor its own pins.

**There is no ALARM net.** The BLD-120A exposes no ALM terminal — "RUN/ALM" is an
LED. `pins::kWheelALARM == kNoPin`.

### Sensors

| Signal | GPIO | Note |
|---|---|---|
| ToF XSHUT FL/FR/RL/RR | 4, 5, 6, 7 | per-sensor reset for address assignment |
| I²C SDA / SCL | 8 / 9 | one bus for everything |
| *(none)* | 1, 2, 3, 14 | freed by the encoder removal; the arm link went to ESP-NOW 2026-08-14 |

### Reserved and free

| Pins | Status |
|---|---|
| 26–37 | flash + octal PSRAM — **board correctly leaves 35/36/37 unconnected** |
| 19, 20 | native USB — unconnected |
| 0, 45, 46 | strapping — unconnected |
| 1, 2, 3, 14 | free — 3 is strapping (JTAG select), 14 is ADC2 and **`bench_ble` now enables WiFi**, so treat 14 as digital-only |
| **43, 44** | UART0 — free **only** in a native-USB-CDC build. `bench_ble` is not one (`CONFIG_ESP_CONSOLE_UART_NUM=0`) |

26 GPIO used, no duplicates, no reserved-pin conflicts. Verified programmatically.

---

## 3. BLD-120A driver interface

### Speed (SV)

The driver has a **native PWM speed input**: manual, Speed Command mode C —
*"speed can be adjusted by PWM control between 1KHz~10KHz, motor speed is
influenced by duty."* No DAC, op-amp or RC filter needed.

- ~~`kSvPwmFreqHz = 5000` — **1–10 kHz is a hard spec range**, not a preference~~
  **[SUPERSEDED — resolved 2026-08-16]** The actual value is
  **`kSvPwmFreqHz = 2000`**, and the correct range is **1–3 kHz**. The
  BLD-120A-specific spec sheet (`docs/BLDC-BLD120A-bldc-motor-controller-specs.pdf`)
  states *"The pulse frequency range: 1-3KHz"*, agreeing with
  `SYS-BLD-120A-manual.pdf` against `BLD-120-English-version.pdf`'s 1–10 kHz.
  **The 5 kHz this document used to specify was out of spec.** `pins.h` is right.
  The datasheet also advises a **2 %–90 % duty range**, with 90 % duty giving
  maximum speed.
- 1–10 kΩ series resistor between GPIO and SV (manual FAQ A). 1.5 kΩ in use,
  fitted as R7 on the Driver PCB.
- ~~**SV is a high-impedance voltage input.**~~ **[SUPERSEDED — treat as
  UNVERIFIED]** The diode test of 2026-08-05 read open in both directions, but a
  later powered test on the same terminals gave conducting readings, and the two
  cannot both be right. `pins.h` records this contradiction; this section
  originally reported only the first result. It does not matter in practice —
  3.3 V PWM at 2 kHz drives all four motors through the adapters, verified by
  behaviour. Re-measure only if you need the driver's true input model for a
  redesign.

  What *is* still established: the old "pot-wiper drags it down" claim and the
  2.59 V figure behind it were the ESP32's weak DAC on the WROOM-32D bench rig,
  not the driver.

### Control lines (EN / BRK / F-R) — opto-isolated, idle near 5 V

Each is an optocoupler LED fed from the driver's internal rail. Measured
2026-08-05: pull-up ≈10 kΩ, ≈440 µA when pulled to COM. **The ESP32-S3 is not
5 V tolerant** — these must never connect straight to a GPIO.

### Polarity (bench-confirmed 2026-07-15, datasheet-confirmed 2026-08-05)

| Line | Asserted state at the driver pin | Meaning |
|---|---|---|
| EN | LOW (connected to COM) | motor enabled |
| BRK | LOW (connected to COM) | brake applied |
| F/R | HIGH (released) | forward |

### Onboard trims — both matter

| Trim | Function | Required setting |
|---|---|---|
| **RV** | speed pot, sums with external input | **fully anticlockwise (left)** — external speed control *fails* otherwise (manual, stated 3×) |
| **P-sv** | overload trip point. Marked in **watts (30–120 W)** on one revision, **amps (1.6–8 A)** on another — same setting | **5 A ≡ 120 W at 24 V.** Too high *or* too low trips the red LED and the motor won't run |
| **ACC/DEC** | acceleration & deceleration ramp, **0.3–15 s** | **minimum (0.3 s)** |

P-sv is the *only* hardware overload protection on this drivetrain. It is not a
speed trim, despite what earlier bench notes claimed.

> **⚠️ [ADDED 2026-08-16] This table used to list two trims. There are three.**
> The **ACC/DEC** potentiometer ramps every speed change over anywhere from 0.3 to
> 15 seconds, and **the positions of all four drivers are unrecorded.** A long
> ramp would invalidate `DeadReckonOdometry`'s assumption that the wheel follows
> the command immediately, and would be indistinguishable from stiction. See
> [`hardware/startup.md`](hardware/startup.md) §6. **[VERIFIED — the trim exists
> and its range; HYPOTHESIS — that it explains any observed behaviour.]**

---

## 4. Transistor adapter (×4) — required between PCB and driver

Converts 3.3 V push-pull GPIO into an open-collector pull to COM, and keeps the
driver's ~5 V rail off the ESP.

```
GPIO ──/\/\/\── 10 kΩ ──┬── Base
                        │
                     100 kΩ          ← gate/base pulldown: CRITICAL.
                        │              Holds the transistor OFF while the GPIO is
                       COM             Hi-Z at boot, reset, or unplugged.
Collector → driver input
Emitter   → COM
```

Pass-through, same pin order both sides (`BRK · EN · F/R · COM · SV`):

| Pin | Treatment |
|---|---|
| 1 BRK, 2 EN, 3 F/R | transistor as above |
| 4 COM | direct wire |
| 5 SV | 1.5 kΩ series resistor |

**The transistor inverts every control line.** Handled in firmware by the single
switch `fal::kControlViaMosfet` in `Bld120aMotor.h`, which derives all four
polarity constants and forces push-pull gate drive. Verified by `static_assert`.

**Device:** **2N3904** (NPN). Base current (3.3 − 0.7)/10 k = 260 µA against a
440 µA load — saturates hard.

> ⚠️ **BC547 is C-B-E; 2N3904 is E-B-C** (flat face toward you, legs down).
> Identical packages, mirrored pinouts.
>
> **[UPDATED 2026-08-16]** This is no longer a free choice. The adapter is now a
> fabricated board — `KiCad/Driver PCB/` — whose footprint is
> `TO-92_Inline_Wide_**EBC**` with a 2N3904 symbol. **A BC547 dropped into those
> holes unrotated swaps collector and emitter** and reproduces exactly the fault
> described below. Use 2N3904.

> **[SUPERSEDED 2026-08-16]** The hand-wired adapter described in this section
> was fabricated as the **Driver PCB** (42.8 × 33.8 mm, ×4). Component values are
> unchanged — 10 kΩ base, 100 kΩ pulldown, 1.5 kΩ on SV — and the pin order still
> matches Wheel Drive J4–J7. See [`hardware/boards.md`](hardware/boards.md) §2
> for the netlist-derived schematic and the per-channel diagnostic procedure.

### The wiring error that cost an evening (2026-08-05)

The first adapter was built like this, and the motor would not run at all:

```
WRONG                                RIGHT
ESP ──10k── B                        ESP ──10k──┬── B
            C ──100k── COM                      │
            E ───────── driver                100k
                                                │
                                               COM
                                                C ───────── driver
                                                E ───────── COM
```

Two faults at once: **C and E swapped**, and the **100 kΩ on the collector instead
of the base**. The transistor did nothing, EN never asserted, and the driver sat
happily idle showing a green LED — no alarm, because from its point of view it had
simply been told to stop.

**Diagnostic signature, for next time:**

| Measurement | Healthy | What we saw |
|---|---|---|
| base → COM, GPIO high | **~0.7 V** (junction clamps) | **1.678 V** — junction not conducting |
| collector → COM, enabled vs disabled | huge change | **1.069 → 0.945 V** — barely moves |

A base that will not clamp at ~0.7 V means the B-E path to COM is broken. A
collector that does not change between states means the transistor is not
switching. Nothing was damaged — currents were microamps throughout.

---

## 5. I²C bus — one bus, shared by everything

| Device | Address | Collision handling |
|---|---|---|
| 4× VL53L0X ToF | `0x29` ×4 | **XSHUT re-addressing** — held in reset, brought up one at a time (`Vl53l0xArray`) |
| ~~TCA9548A~~ | ~~`0x70`~~ | **Removed.** Fitted for the encoders; both retired. `pins::kMuxAddr` and the mux code were deleted 2026-08-31 |
| BNO085 IMU | `0x4A` | — |
| ADS1115 | **`0x48`** | ADDR → GND. **Do not leave floating or tie to SDA** — that gives `0x4A` and collides with the IMU |

### Base ↔ ESP-ARM link: ESP-NOW

The three-wire UART on GPIO1/2 never passed a byte and was retired **2026-08-14**.
Commands now go by radio.

| | |
|---|---|
| Transport | ESP-NOW, WiFi **channel 1**, STA mode, no AP |
| Payload | plain text, **NUL-terminated** (`strlen(cmd) + 1`) |
| Base MAC | `14:C1:9F:3B:7B:E4` — checked at boot against `SELF_ESP_MAC` |
| Arm MAC | `3C:DC:75:5C:8B:08` |

**Four commands, and no more.** The arm is already flashed to parse exactly
these, so the strings are an interface, not an implementation detail:

```
grab        release        home_setup        estop
```

Replies arrive as text on a callback: `done_grab`, `done_release`, `done_home`,
`busy`, `stopped`, `failed:<reason>`, `rejected:<reason>`.

**What this cost.** Bluepad32/BTstack owns the 2.4 GHz radio for the gamepad, and
WiFi STA now shares it through the coexistence scheduler. Expect the pad to be
marginally less responsive and to drop slightly more often than on the UART
build. That is a real price paid to avoid three wires — if it becomes
intolerable, the answer is to fix the wiring, not to tune the radio.

**Busy interlock.** `busy` from the arm suppresses the *next* ordinary command
and then clears, so one press gets one refusal rather than a queue that fires
against a state that has since changed. E-stop is exempt and always sends: an
E-stop a status message can suppress is not an E-stop.

**Gone with the UART.** The arm's per-axis jog (`e`/`r`/`E`/`R`) and flip
(`f`/`F`) characters are not part of the four-command protocol, so D-pad arm jog
and the LT/RT flips no longer exist. The D-pad is drive-only.

### Encoders — removed 2026-08-13

Four AS5600 on a TCA9548A mux, never made to work: all four share address `0x36`
with no address pin, the board commons SDA/SCL, and isolating them needed eight
trace cuts at the encoder connectors. Resistance checks found two modules at
60 kΩ and 165 kΩ against 280 kΩ for the healthy pair, and the parasitic-power
signature pointed at a missing VCC connection.

> **[CORRECTED 2026-08-16] The missing VCC is on the PCB, not in the loom.**
> `pin 1` of every 1×04 encoder connector — J1, J11, J15, J18 — is unconnected in
> the netlist. That header carries SDA, SCL and GND only. The AS5600's sole power
> path was the separate 1×03 analog connector, which is exactly the parasitic-power
> signature that was observed. No amount of re-looming would have fixed it.
> **[VERIFIED — netlist]**
>
> A later attempt used an external PCA9548-type mux; it overheated and failed with
> more than two AS5600 attached. **[OBSERVED — Bryan]**

The pin tables are deleted from `pins.h` rather than commented out. GPIO3 and
GPIO14 are now free; GPIO1 and GPIO2 belong to the arm link.

---

## 6. Current sensing

**4× ACS758LCB → ADS1115 (4-channel, 16-bit) → I²C**

This feeds `StallDetector`, which — with no ALM terminal and P-sv as the only
hardware trip — is the main software protection for the drivetrain.

### Why the ACS758 is the right choice — headroom beats sensitivity

The driver is rated **8 A continuous, 30 A instantaneous (<3 s)** (manual p.2).
Sizing the sensor to the *running* current (~0.2–1 A) leaves it blind during
exactly the events worth measuring.

Both candidates, ratiometrically scaled to the board's 3.3 V rail:

| Part | Sensitivity | Noise (current-referred) | Output clips at |
|---|---|---|---|
| **ACS758LCB-050B** | 26.4 mV/A | 0.175 A rms | **±62 A** |
| ACS712-05B | 122 mV/A | 0.114 A rms | **5 A** |

**The resolution gap is 1.5×, not the ~25× a sensitivity comparison implies** —
Hall noise scales with sensitivity, so current-referred noise barely moves between
parts. An earlier revision of this document called the ACS758 "badly oversized".
That was wrong, and this section is the correction.

What each part actually sees:

| Condition | ACS758-050B | ACS712-05B |
|---|---|---|
| 0.5 A running | 1.66 V | 1.71 V |
| 1 A loaded | 1.68 V | 1.77 V |
| **8 A stalled** | 1.86 V | **CLIPPED** |
| **30 A inrush** | 2.44 V | **CLIPPED** |

A clipped sensor cannot tell 5 A from 30 A — the difference between "working hard"
and "something is badly wrong". For a signal feeding a fault trip, that matters far
more than resolving 100 mA at idle.

**Resolution is sensor-limited, not ADC-limited.** ADS1115 at PGA ±2.048 V gives
62.5 µV/LSB = **2.4 mA per count**, 74× finer than the sensor's own noise floor.
Averaging 8 samples brings that floor to ~62 mA — fine enough to spot a seized
caster from the current differential between wheels.

### Remaining choices

1. **Prefer `-050B` (bidirectional) over `-050U`.** DC-bus current is nominally
   one-directional, but applying BRK can push energy back toward the supply. `B`
   costs one bit of range and removes the question.
2. **Supply rail — CONFIRMED 3.3 V.** The board feeds J8/J9/J12/J14/J17 from
   **3.3 V** (`/3V Wheel`). ACS758 is ratiometric, so at 3.3 V a -050B gives
   26.4 mV/A with a 1.65 V zero point — read directly by a 3.3 V ADS1115, no
   divider, no level shifting. Powering it at 5 V instead puts up to 5 V into a
   3.3 V ADC input and needs a divider. ~~Confirm the rail before wiring.~~
   **[VERIFIED — netlist, 2026-08-16: pin 1 of all four connectors is on
   `/3V Wheel`.]**

   Likewise the **ADS1115 address is `0x48` fixed in copper** — J8 pin 5 lands on
   the module's ADDR pin and the board ties it to ground. There is no jumper to
   set and no way to get it wrong. **[VERIFIED — netlist]**
3. The sensor is *observation*, not protection. The real trip chain is the driver's
   P-sv overload trim, then the 10 A fuse, then software.

> ## ⚠️ [ADDED 2026-08-16] None of this is live — the sensors are not wired
>
> The four ACS758 are physically installed **inline with the negative side of the
> motor driver supply**, but their outputs are **not connected to
> J9/J12/J14/J17**. `StallDetector` is reading an ADS1115 that sees nothing.
>
> Everything in this section is a correct analysis of a signal path that does not
> currently exist. Combined with the absence of an ALM terminal and the retired
> encoders, **the base has no drivetrain fault detection at all** — the trip chain
> is P-sv and the fuse, full stop.
>
> Connecting them would be four wires. See `gotchas.md` Open Issue C and
> [`hardware/components.md`](hardware/components.md) §4. **[OBSERVED — Bryan]**

---

## 7. Bill of materials

### Board-mounted (not yet fitted)

| Qty | Part | Where |
|---|---|---|
| 4 | 1×03 male header 2.54 mm | J2, J10, J13, J16 |
| 8 | 1×04 male header | J1, J11, J15, J18, J9, J12, J14, J17 |
| 4 | 1×05 male header | J4–J7 |
| 4 | 1×06 male header | TOF5–8 |
| 2 | 1×10 male header | J8, J19 |
| 2 | 1×22 **female** header | U6 — **socket it, don't solder the DevKit down** |
| 1 | 2-pos 5.08 mm terminal block (Phoenix MKDS-1,5-2-5.08 or equiv.) | J3 |
| 4 | M3 screw + standoff | H1–H4 |

108 male positions ≈ three 40-pin breakaway strips; 44 female ≈ two strips.

### Modules

| Qty | Part | Stage |
|---|---|---|
| 1 | ESP32-S3-DevKitC-1 **N16R8** | move |
| 4 | BLD-120A driver + BLDC motor, 15:1, 150 mm wheel | move |
| 4 | transistor adapter (BC547/2N3904 + 10 k + 100 k + 1.5 k) | move |
| 2 | **TCA9548A** breakout | ~~sense~~ — encoders abandoned, mux no longer needed |
| 4 | AS5600 breakout | ~~sense~~ — **removed 2026-08-13**, see §5 |
| 4 | VL53L0X breakout — **must break out XSHUT** | dock |
| 1 | BNO085 breakout (10-pin) | dock |
| 1 | ADS1115 breakout | sense |
| 4 | ACS758LCB (see §6 open questions) | sense |

**To get wheels turning you need only the "move" rows** plus the J4–J7 headers,
the DevKitC socket, J3 and the standoffs.

---

## 8. Decision log

| Date | Decision |
|---|---|
| 2026-08-04 | Pi 5 becomes the brain; ESPs become I/O. Link watchdog + latch is mandatory. |
| 2026-08-05 | `pins.h` rebuilt from the netlist — the previous map was pre-PCB design intent and did not match the fabricated board (SV on the ToF XSHUT pins, I²C on two BRK lines). |
| 2026-08-05 | PWM resolution 8 → 12-bit; SV carrier 20 kHz → 5 kHz (20 kHz was outside the driver's 1–10 kHz spec). |
| 2026-08-05 | No DAC / op-amp / level shifter for SV — the driver takes PWM natively and SV is high-impedance. |
| 2026-08-05 | Encoders via TCA9548A rather than AS5600L, to keep the existing AS5600 stock. |
| 2026-08-13 | **Encoders abandoned.** Never worked on the fabricated board; no wheel-speed feedback, current sense is the only drivetrain fault signal. |
| 2026-08-13 | Base↔arm link on UART1 GPIO1/2 — *not* GPIO43/44, which `bench_ble`'s IDF console occupies. |
| 2026-08-14 | **Base↔arm moves to ESP-NOW** (channel 1, plain text). The UART never passed a byte. Accepts BT/WiFi coexistence on the gamepad radio as the price. |

## 9. Open items

- [ ] **Minimum speed.** Break-away ≈0.78 V → ~413 mm/s at the wheel, already
      above the 300 mm/s target, and one 20 ms tick moves 8.3 mm against an
      8 mm centring tolerance. Likely a gearing/wheel-diameter problem, not a
      firmware one. The driver's PID speed loop may rescue it — **settle with the
      REF+ → 1 kΩ → SV pot sweep.**
- [x] ~~`max_lin_mm_s = 300` is wrong; actual is ~1400 mm/s at full command.~~
      **Done.** `config.h:195` sets `c.max_lin_mm_s = 1231.0f`; the `300.0f` in
      `DeadReckonOdometry.h` is only the struct default and is overridden by
      `makeOdometryCal()`. Accuracy is still ~±6 % — `gotchas.md` Open Issue B —
      but docking was restructured so the park point no longer depends on it.
- [ ] `main.cpp` still passes one shared EN/BRK pair to all four motors. **The
      board gives each wheel its own** (§2), so this leaves independent per-wheel
      shutdown unused.
- [x] ~~ACS758LCB-**050B** confirmed as the right part (§6); still to confirm the
      supply rail is 3.3 V and set ADS1115 ADDR→GND for `0x48`.~~ **Both resolved
      from the netlist, 2026-08-16** — the rail is 3.3 V and `0x48` is fixed in
      copper. See §6.
- [ ] Confirm the motor's rated watts, to set P-sv. **Still open, and it blocks
      the start-up procedure** — see [`hardware/startup.md`](hardware/startup.md) §6.

**Added 2026-08-16, from the netlist cross-check:**

- [ ] The **red mushroom button is wired as an enable, not an E-stop.** One wire
      to fix. `gotchas.md` §18.
- [ ] The **Arm PCB's servo headers S1–S4 are dead in firmware** — it drives a
      PCA9685 that has no connector on the board. `gotchas.md` §17.
- [ ] **Two custom KiCad libraries are missing** (`My_30.007_Library`,
      `HengLi's Footprint Library`). Boards can be re-ordered as-is but not
      cleanly re-synced schematic→layout.
      [`hardware/fabrication.md`](hardware/fabrication.md) §3.
- [ ] The **BNO085 module pinout is not captured anywhere** — J19 exposes
      3V3·GND·SCL·SDA on a generic 10-pin header, and some common breakouts put a
      regulator *output* on pin 2. Verify before seating.
      [`hardware/boards.md`](hardware/boards.md) §1.

---

## Bring-up gotchas that cost real time (2026-08-06)

Two failures that both presented as something other than what they were. Both
are worth reading before debugging a silent or dead board.

### 1. Missing ESP-to-PSU ground presented as a GPIO0 strapping fault

**Symptom:** the ESP booted `rst:0x15,boot:0x3 (DOWNLOAD(USB/UART0))` on every
reset, so the application never ran. Uploads worked without touching BOOT, which
is itself the tell — a board that always boots to download never needs the button.

**Cause:** the ESP had no ground connection to the motor PSU. With no shared
reference, GPIO0 had nothing sane to sit at and read low at reset.

**Why it misleads:** everything points at GPIO0. The netlist leaves that pin
unconnected, so the obvious conclusion is a solder bridge, and you go looking for
copper faults. The isolating test is the fast one: lift the module off the PCB
and reset it standalone. `0x8` off the board and `0x3` on it localises the fault
to the board in one move.

**Boot modes worth memorising:**

| Code | Meaning |
|---|---|
| `boot:0x8 (SPI_FAST_FLASH_BOOT)` | normal — the app is running |
| `boot:0x3 (DOWNLOAD(USB/UART0))` | GPIO0 was low at reset; app never runs |

### 2. HWCDC blocks forever if the host stops reading

**Symptom:** the board goes permanently silent — no banner, no command response,
and esptool fails with `No serial data received`. Only a physical USB replug
clears it. Looks exactly like dead firmware or a dead board.

**Cause:** with `ARDUINO_USB_MODE=1`, `Serial` is HWCDC, which **blocks** when its
TX buffer fills and no host is draining it. Any sketch that prints unprompted
(a heartbeat, periodic telemetry) will fill that buffer the moment the terminal
closes, then hang inside `Serial.printf`.

**Fix, and it belongs in every S3 sketch that prints unprompted:**

```cpp
Serial.setTxTimeoutMs(0);   // never block; discard instead
```

Losing output to a terminal that is not attached is always the right trade
against wedging the controller. This is the same principle as `LinkWatchdog`,
one layer down: a peer that stops listening must never be able to stall us.

### 3. DTR is the IO0 strap on USB-Serial-JTAG

When scripting the serial port on an ESP32-S3, open it with **DTR and RTS LOW**.
Asserting DTR is esptool's "set IO0" step and forces the chip into download mode.
A probe that sets `dtr=True` will put the board into the bootloader and then
report it as silent — a self-inflicted fault that reads as a hardware one.

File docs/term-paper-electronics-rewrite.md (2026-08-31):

# Term paper — electronics & power section, rewritten

**Scope:** §II.C.3 (Electronics & Motion Control System), the battery-sizing part of §III.A,
a new electrical results subsection for §IV, and a limitations paragraph for §V.
Everything here is drop-in prose for the paper, followed by a change log and the
list of numbers still to be measured.

**Sourcing:** every figure is traced to `docs/hardware/components.md`,
`docs/hardware/startup.md`, `docs/hardware-architecture.md` or `docs/gotchas.md`.
Values that the repo marks as unrecorded are written as **[EST]** in the tables and
must be either measured or removed before submission — see *Open numbers* at the end.
Do not submit an **[EST]** as a fact.

---

## §II.C.3 — Electronics & Motion Control System (condensed, ~300 words)

*(Use this version if the section must stay to one paragraph block. The long-form
version follows below — keep only one.)*

The electronics architecture is a two-controller distributed system built on the staged
power tree of Fig. 6, which separates the 36 V main power system from a USB-fed logic
system joined to it at a single point. Three custom PCBs were designed and fabricated
for it: a base Wheel Drive board (Appendix A), an Arm Subsystem board (Appendix B), and
four identical Driver adapter boards (Appendix C). A custom 36 V, 10 Ah lithium-ion pack
with integral BMS feeds a 40 A main switch and a reverse-polarity and bulk-capacitance
stage supplying the main 36 V bus. Three independently protected branches descend from
that bus: a 30 A fuse ahead of the 36→24 V converter feeding the four BLD-120A brushless
drivers; a 20 A latching enable switch ahead of the 36→12 V converter feeding the two
BTS7960 H-bridges and arm-extension motors M5–M6; and an 8 A fuse ahead of the 36→5 V
converter feeding the PCA9685 expander and four GX3345BLS flipper servos S1–S4 on the
arm board. Each driver carries a further 10 A fuse on the 24 V sub-bus, so a single
motor fault clears locally, and each driver's P-sv overload trim is set to the motor's
rated 5 A (120 W at 24 V). Gating the 12 V branch at its converter input also staggers
inrush: all three converters charging together latched the pack BMS, whereas energising
the third separately keeps the transient below it. The drivers' optocoupler inputs idle
near 5 V, so each control line is switched by a 2N3904 on its Driver board, whose 100 kΩ
pull-down holds every motor disabled while a controller is unpowered or in reset. Each
branch returns through its own ground to the main VBat− star bus, meeting the logic
ground plane at the single tie of Fig. 6; without that bond, made at the Wheel Drive
board's J3 terminal, the base controller does not boot.

---

## §II.C.3 — Electronics & Motion Control System (long form)

*(Replaces the existing subsection in full.)*

The electronics architecture is a two-controller distributed system built around a
staged step-down power tree (Fig. 6). Control authority is split between a **base
controller**, which owns the drivetrain and the docking state machine, and an **arm
controller**, which owns the extension and clamping hardware. Both are ESP32-S3-DevKitC-1
(N16R8) modules.

**Power distribution.** DC power is supplied by a custom-built 36 V, 10 Ah lithium-ion
pack with an integral battery management system (BMS). The pack feeds a 40 A main switch,
from which three buck converters step 36 V down to the three service rails in parallel:
a **24 V** rail supplying the four BLD-120A brushless motor drivers, a **12 V** rail
supplying the two arm-extension wormgear motors through their BTS7960 H-bridges, and a
**5 V** rail supplying the four GX3345BLS (45 kg·cm) flipper servos together with the
logic supplies of both H-bridges. Rail assignments and loads are given in Table 5.
The parallel topology was chosen over a cascaded 36 → 24 → 12 → 5 V chain so that a
fault or transient on one rail cannot propagate to the others, and so that each
converter's current rating is set only by its own load.

The two ESP32-S3 controllers are powered separately over USB rather than from the pack.
This isolates the logic domain from motor-supply transients — the dominant noise source
in the system — at the cost of an external supply requirement that is addressed in §V.
Because the controllers and their sensors are not pack-fed, the logic domain contributes
no load to the battery budget in §III.A.

**Protection and sequencing.** Protection is layered. Each BLD-120A carries a hardware
overload trim (P-sv) set to the motor's rated 5 A ≡ 120 W at 24 V, which trips the driver
before its 8 A continuous rating is exceeded. A pack fuse sized per Table 6 protects the
main conductor, and the 40 A main switch doubles as the manual isolator. Signal-level
protection is provided by the driver interface described below, which holds the motors
disabled whenever the controller is unpowered or in reset.

Power-up sequencing is a deliberate design feature rather than an operating convenience.
All three converters present their input capacitance to the pack simultaneously at
switch-on, and the resulting inrush transient was observed to trip the pack's BMS into a
latched fault. The 12 V branch was therefore moved behind a latching panel switch so
that only two converters energise at main-switch time and the third is brought up a
moment later, staggering the transient below the BMS threshold. A pre-charge resistor
is identified in §V as the more robust permanent fix.

**Motor drive interface.** Each BLD-120A is commanded over five lines — speed (SV),
direction (F/R), enable (EN) and brake (BRK) referenced to the driver common (COM). The
driver's control inputs are optocoupler inputs idling near 5 V, and the ESP32-S3 is not
5 V tolerant, so the two domains are separated by a custom four-off adapter PCB. Each
control line drives a 2N3904 in open-collector configuration through a 10 kΩ base
resistor, with a **100 kΩ base-to-common pull-down** that holds the transistor off
whenever the GPIO is high-impedance. This makes the interface fail-safe by construction:
with the controller unpowered, unflashed or in reset, all four motors read as disabled.
SV is driven directly through a 1.5 kΩ series resistor as a 2 kHz PWM waveform, within
the driver's specified 1–3 kHz input range and 2–90 % duty band; no DAC, filter or
external speed pot is required.

**Sensing.** The base carries four upward-facing VL53L0X time-of-flight sensors, one at
each corner of the chassis, which are polled in sequence to infer the robot's position
and orientation relative to the underside of the trolley during approach. All four share
a single I²C bus and the same factory address, so each sensor's XSHUT line is held in
reset and released one at a time at boot, allowing a unique address to be assigned per
corner. A BNO085 inertial measurement unit on the same bus supplies orientation, which
the firmware fuses with commanded wheel velocity to maintain a dead-reckoned position
estimate between sensor updates. Four further ToF sensors, eight limit switches and a
PCA9685 PWM expander sit on the arm controller, where the ToF sensors detect the trolley
edge and the limit switches confirm contact at the end of retraction.

Per-wheel current sensing is provided for by four ACS758LCB-050B Hall-effect sensors
inline with the motor-supply return, feeding a 16-bit ADS1115 ADC. The ±50 A part was
selected over a more sensitive ±5 A alternative because the driver is rated to 30 A
instantaneous: a 5 A sensor saturates during precisely the stall and inrush events worth
detecting, whereas Hall noise scales with sensitivity, so the resolution penalty of the
larger part is only about 1.5×. The signal path is not yet commissioned (§V).

**Command and communications.** Operator commands originate from an Xbox controller
paired to the base over Bluetooth Low Energy. The base then issues clamping commands to
the arm controller over **ESP-NOW** on WiFi channel 1, using a deliberately minimal
four-command protocol — `grab`, `release`, `home_setup`, `estop` — with acknowledgement
replies (`done_*`, `busy`, `stopped`, `failed:<reason>`). A radio link was adopted after
a three-wire UART between the controllers proved unreliable in the assembled machine. The
trade-off is explicit: the BLE gamepad stack and the WiFi radio now share the same 2.4 GHz
front end through the coexistence scheduler, which costs a small amount of gamepad
responsiveness. Two interlocks bound the failure modes — a `busy` reply suppresses the
next ordinary command so that a queued instruction cannot execute against a state that
has since changed, and the E-stop command is exempt from that suppression on the
principle that a stop a status message can swallow is not a stop.

---

## §III.A — Electrical modelling (replaces the "Battery Sizing" paragraph)

*(Insert after the motor/gearbox paragraph, before Thermal Analysis.)*

**Rail loading.** The load on each rail is fixed by the components it feeds (Table 5).
The 24 V rail dominates: four 120 W motors at their rated 5 A draw 20 A, or 480 W, with
all four wheels working. The four drivers can supply 8 A each, giving 32 A of installed
capacity against a 20 A demand, so the drivers are not the binding constraint — the
converter is.

**TABLE 5: Rail allocation and loading**

| Rail | Loads | Continuous load | Worst case | Basis |
|---|---|---|---|---|
| 24 V | 4× BLD-120A + BLDC gearmotor | 20 A / 480 W | 32 A driver limit; 30 A instantaneous < 3 s | Motor rated 5 A at 24 V |
| 12 V | 2× wormgear extension motor via BTS7960 | **[EST]** 10 A / 120 W | H-bridge rated 43 A | **[EST]** — motor spec unrecorded |
| 5 V | 4× GX3345BLS servo + 2× BTS7960 logic | **[EST]** 4 A / 20 W | **[EST]** 10 A / 50 W (four servos stalled) | **[EST]** — servo datasheet unconfirmed |
| USB | 2× ESP32-S3 + all sensors | ~1 A total | — | Not pack-fed; excluded from battery budget |

**Pack current by operating phase.** Peak demand is phase-dependent, because the docking
sequence holds the robot stationary while the arms actuate; drive and clamp loads are not
commanded concurrently. Converting rail power to pack current must include converter
efficiency, taken as η = 0.85:

    I_pack = P_rail / (V_pack × η)

| Phase | Rail power | Pack current |
|---|---|---|
| Driving under load (four wheels at rated torque) | 480 W | 480 / (36 × 0.85) = **15.7 A** |
| Docking (arms extending, servos flipping) | 140 W **[EST]** | **4.6 A** |
| Absolute worst case (all loads concurrent, not commanded) | 650 W **[EST]** | **21.2 A** |

The 15.7 A driving figure, not the 21.2 A arithmetic worst case, is the number the pack
and its conductors must sustain continuously.

**Battery sizing.** Taking a duty-weighted average draw of 250 W over a working cycle —
the drivetrain loaded for roughly half the cycle, plus docking activity — and requiring
one hour of runtime with a 20 % state-of-charge reserve (usable depth of discharge
DoD = 0.8):

    C = P × t / (V × DoD × η) = 250 × 1 / (36 × 0.8 × 0.85) = 10.2 Ah

The selected 36 V 10 Ah pack (360 Wh) therefore sits essentially at the sizing point,
delivering approximately 59 minutes at this duty. Sizing to the arithmetic worst case
instead would demand a far larger pack for a condition the control sequence never
commands; the one-hour figure is quoted against realistic duty and is stated as such.
Note that including converter efficiency raises the requirement by about 18 % over the
ideal-conversion calculation, which is the difference between a pack that meets the
requirement and one that narrowly misses it.

**Fuse and conductor sizing.** Fuses are sized at approximately 1.5× the continuous
current of the branch they protect and below the ampacity of the conductor they sit on:

**TABLE 6: Overcurrent protection**

*(Values as drawn in Fig. 6. Branch currents are referred to the 36 V side, since all
three fuses sit upstream of their converters.)*

| Element | Continuous current | Device (Fig. 6) | Note |
|---|---|---|---|
| Drivetrain branch | 15.7 A | 30 A fuse | ~1.9× margin; carries converter inrush as well as load |
| Each BLD-120A | 5 A rated at 24 V | 10 A fuse ×4 | **Must be time-delay** — the driver draws 30 A instantaneous for < 3 s, which opens a fast-blow 10 A on every start |
| Arm branch | 3.9 A **[EST]** | 20 A enable switch | **No fuse fitted.** A switch rating is not overcurrent protection — a ~10 A fuse belongs here |
| Servo branch | 1.6 A **[EST]** at 36 V | 8 A fuse | Sized ~5× above the branch load; ~3 A would actually protect it |
| Main conductor | 15.7 A | 40 A main switch | Switch is the isolator; branch fuses provide selectivity below it |
| Pack conductor gauge | 15.7 A | **[EST]** ≥ 10 AWG | Ampacity plus derating in an enclosed chassis |

Protection is selective by design: the per-driver fuses are the smallest devices in the
chain and clear first, so a single seized wheel isolates that motor while the remaining
three continue, and the 30 A branch fuse acts only on a fault involving the converter or
the sub-bus itself.

The layered scheme means an overload on a single motor is caught by that driver's own
P-sv trim in isolation, while the pack fuse protects only against a fault severe enough
to involve the main conductor.

---

## §IV — new subsection C: Electrical characterisation

*(Insert after the existing experiments table. Table 7 reports what has been established
on hardware; Table 8 states the instrumentation still outstanding, which is the honest
position and is better than an empty results section.)*

**TABLE 7: Electrical results obtained**

| Test | Objective | Result |
|---|---|---|
| Drivetrain speed ceiling | Establish the geometric maximum from gearing | 3000 RPM ÷ 15 over a 150 mm wheel = 1571 mm/s; the configured 1231 mm/s command limit is 78 % of ceiling, confirming it is physically attainable |
| Break-away speed | Find the minimum commanded speed at which wheels turn | ≈ 413 mm/s; wheels do not rotate slowly below this, they do not rotate at all — attributed to static friction and load, not to the drive electronics |
| Power-up transient | Determine whether the BMS trip at switch-on is inrush-related | Trip reproduced with all three converters energising together; eliminated by staggering the 12 V branch behind a latching switch |
| Logic/power ground bond | Diagnose repeated controller boot failures | With the USB-powered controller and the 24 V-powered drivers on separate grounds, the controller booted to download mode on every reset; bonding the two grounds at the board terminal restored normal boot |
| Driver interface verification | Confirm the open-collector adapter switches correctly | Base-to-common clamps at ≈ 0.7 V when asserted; a non-clamping junction reading 1.68 V identified a transposed collector/emitter on the first assembly |
| Docking sequence, end-to-end | Confirm sensing and inter-controller command path under real conditions | Full approach, edge detection and clamp cycle completed on hardware; radio link stable after command pacing was added |

**TABLE 8: Instrumentation planned**

| Test | Method | Validates |
|---|---|---|
| Pack current under load | Clamp meter on the pack lead, driving loaded and unloaded | The 15.7 A drive-phase prediction and the 25 A fuse rating |
| Runtime to reserve | Log pack voltage at typical duty until 20 % SoC | The 10.2 Ah sizing calculation |
| Rail sag at peak | Meter 5 V at the arm terminal block during a four-servo flip; 24 V during four-wheel break-away | Converter current ratings, which are currently unrecorded |
| Thermal soak | IR thermometry of drivers and converters after one hour of continuous operation | The passive-heatsink claim in §III.A, presently unmeasured |
| Radio link quality | Command-to-motion latency and dropout rate over a docking cycle, with BLE and WiFi coexisting | The cost of the ESP-NOW link accepted in §II.C.3 |
| Current-sense commissioning | Connect the four ACS758 outputs, then calibrate the stall threshold against a loaded trolley | Restores the only drivetrain fault signal in the design |

---

## §V — limitations paragraph to add

*(Insert into the Discussion, before the closing paragraph. Stating known faults with
their fixes reads as engineering maturity; omitting them and having a grader find them
does not.)*

Three limitations in the present build are identified and carried forward. First, the
panel-mounted latching switch that gates the 12 V arm rail is wired to its
normally-open contact, so pressing it energises the rail rather than isolating it, and
it does not switch the 24 V traction rail at all. It is therefore an enable, not an
emergency stop; moving the rail to the normally-closed contact and extending the
interlock across the traction rail is a single-wire change and is the first item of
future work. Second, the four current sensors are installed in the motor return path but
their signal outputs are not yet connected, so the software stall detector currently
observes no signal and drivetrain protection rests on the driver overload trims and the
pack fuse alone. Third, the two controllers are powered externally over USB rather than
from the pack; a dedicated isolated logic rail is required before the platform can
operate untethered for a full shift. None of these affects the results reported in §IV,
but each bounds the conditions under which the prototype should be operated.

---

## Change log — what this rewrite fixes

| # | Original text | Change | Why |
|---|---|---|---|
| 1 | "The sensors when excluded in order inform the controller … relative to the trolley/" | Rewritten as a complete sentence with the XSHUT addressing explained | The sentence was ungrammatical and ended mid-clause |
| 2 | Peak current stated as 20 A, then calculated as 22.8 A | Single phase-based table; 15.7 A continuous, 21.2 A arithmetic worst case | The paper contradicted itself two lines apart |
| 3 | Servos budgeted at 4 × 25 W | Rewritten around the GX3345BLS 45 kg·cm servos actually fitted, with nominal and stall figures separated | The old figure matched no fitted part |
| 4 | 820 / 36 = 22.8 A | η = 0.85 included in every rail-to-pack conversion | Ignoring converter loss understates pack current by ~18 % |
| 5 | Battery pack described as "2–3 C (20–30 A) discharge" | Described as custom-built with an integral BMS; no discharge rating claimed | The repo records the pack as custom with **no documented C-rating**. The figure could not be supported |
| 6 | Inter-controller link absent; "shared I2C bus" implied it | ESP-NOW link, four-command protocol, interlocks, and the coexistence trade-off stated | The link is the central architectural decision of this section and was missing. I²C is the *sensor* bus |
| 7 | No power budget table | Tables 5 and 6 added | Every other analysis section carries a variables table; this one did not |
| 8 | "Fuses were sized according to the maximum safe as well as operating loads" | Explicit 1.5× rule, values, and conductor ampacity | The original asserted a method without stating it |
| 9 | "Reverse current protection was designed into the power system" | Removed | No such component appears anywhere in the hardware documentation. Re-add only if one is physically fitted, with its part number |
| 10 | Circuit breaker described as main switch | 40 A main switch, as built | Terminology matched neither the part nor the drawing |
| 11 | Motor drive interface not described | Adapter PCB, fail-safe pull-down, 2 kHz PWM within the 1–3 kHz spec | This is the section's strongest original engineering content and was entirely absent |
| 12 | ESP32 power source unstated | Stated as USB, with the isolation rationale and the limitation | A grader will ask where the logic power comes from |
| 13 | Inrush/BMS behaviour unstated | Presented as a designed sequencing decision | Turns an operational quirk into a defensible design choice |
| 14 | Wheel diameter 152 mm | 150 mm | Repo records 150 mm; the speed ceiling arithmetic depends on it |
| 15 | "powers distribution", "convertors", "X-box", "low power Bluetooth", "4 … at each corner" | Corrected throughout | — |
| 16 | No electrical results | §IV.C added, split into obtained and planned | The gap you identified |

---

## Open numbers — measure or delete before submission

Each of these appears as **[EST]** above. An estimate presented as a measurement is a
much worse error than an acknowledged gap.

1. **Buck converter models and current ratings** (all three). Printed on the units —
   read them off. The 24 V unit must carry 20 A and the 5 V unit must survive four
   servos flipping together; if either is undersized, that is itself a finding worth
   reporting.
2. **Arm wormgear motor rating** (voltage, current, power). Sets the 12 V row of Table 5.
3. **GX3345BLS stall current at 5 V.** Determines the 5 V worst case and whether the
   rail is adequately sized.
4. **Pack fuse rating and physical location.** The repo mentions a 10 A fuse; a 10 A
   fuse on the pack conductor would open during normal four-wheel driving at 15.7 A.
   Either it protects a branch rather than the main, or it is wrong. Resolve this
   before submitting Table 6 — it is a genuine safety item, not just a paper issue.
5. **Battery pack internals** — cell count, chemistry, BMS continuous and peak rating.
   Until these exist, no C-rating claim can appear in the paper.
6. **Pack conductor gauge.** Measure and confirm against 15.7 A continuous.

## Appendix contents and labels

The paragraph cites three appendices. Label them this way in the paper so the callouts
resolve, and put schematic before layout within each:

| Label | Board | Files in `KiCad/` | What the text points at |
|---|---|---|---|
| **Appendix A** | Wheel Drive PCB (base) | `Wheel Drive PCB/` — schematic PDF + layout | J3 ground-bond terminal; J4–J7 driver headers; I²C bus and ToF XSHUT lines; ADS1115 and current-sense headers |
| **Appendix B** | Arm Subsystem PCB | `Arm Schematic.pdf`, `Arm PCB Layout Draft Size.pdf` | J3 5 V servo supply terminal; BTS7960 headers J1/J2; SW1–SW8 limit switches; ToF headers |
| **Appendix C** | Driver adapter PCB (×4) | `Driver PCB/` — schematic + layout | The 2N3904 open-collector stage, 10 kΩ base, 100 kΩ pull-down, 1.5 kΩ SV series resistor |

Two notes on presenting them:

1. **Appendix C is the one that earns marks.** It is the only board whose design contains
   an argued engineering decision — the fail-safe pull-down — so give it a caption that
   states that, rather than letting it sit as an unlabelled schematic.
2. **The two custom KiCad libraries are missing** from the repo (`My_30.007_Library`,
   `HengLi's Footprint Library`), which affects re-fabrication but not the exported PDFs
   already in `KiCad/`. Export appendix figures from those PDFs, not from a fresh
   schematic→layout sync.

## Figure 6

The existing power-architecture diagram needs three corrections to match this text:
the 12 V branch behind the latching switch (drawn on the converter **input** side),
the two controllers shown on USB and outside the pack tree, and the ESP-NOW link drawn
between the controllers in place of any wired connection.

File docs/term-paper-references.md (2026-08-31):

# Term paper — reference list (IEEE style)

**Status key**

- **✓ verified** — URL and details checked against the live source on 21 Aug 2026.
- **⚠ verify** — a standard work cited from a known bibliography. The content is right;
  confirm the **edition and year** against the copy you actually consult before submitting.
- Do not cite anything here you have not at least looked at. A reference list is a claim
  that you read them.

Numbering below is grouped by section for convenience. Renumber in citation order —
IEEE requires references numbered in the order they first appear in the text.

---

## A. Introduction and context (§I, §II)

[1] Grand View Research, "Autonomous mobile robots market size, share & trends analysis
report," Grand View Research, San Francisco, CA, USA, 2025. [Online]. Available:
https://www.grandviewresearch.com/industry-analysis/autonomous-mobile-robots-market
[Accessed: Aug. 21, 2026]. **✓ verified**

[2] ABB Robotics, "Flexley Mover AMR P603," ABB Ltd. [Online]. Available:
https://www.abb.com/global/en/areas/robotics/products/mobile-robots/flexley-mover/amr-p603
[Accessed: Aug. 21, 2026]. **✓ verified** — *note: the P603 is an **ABB** product; the
current draft attributes it to no manufacturer. Payload 1500 kg, top speed 2 m/s,
±5 mm positioning, ISO 3691-4 compliant — all citable from this page.*

[3] Seegrid Corporation, "Palion Tow Tractor S7 autonomous mobile robot," Seegrid Corp.,
Pittsburgh, PA, USA. [Online]. Available:
https://seegrid.com/autonomous-mobile-robots/tow-tractor-s7-amr/
[Accessed: Aug. 21, 2026]. **✓ verified** — *the draft spells this "Seagrid". It is
**Seegrid**, and the product line is **Palion**. Fix in §I.*

[4] B. E. Ilon, "Wheels for a course stable selfpropelling vehicle movable in any desired
direction on the ground or some other base," U.S. Patent 3 876 255, Apr. 8, 1975.
**✓ verified**

[5] Industrial trucks — Safety requirements and verification — Part 4: Driverless
industrial trucks and their systems, ISO 3691-4:2023, International Organization for
Standardization, Geneva, Switzerland, 2023. **✓ verified** — *worth citing in §V: it is
the standard your safety discussion is measured against, and naming it shows you know
the prototype is not yet compliant.*

[6] R. Siegwart, I. R. Nourbakhsh, and D. Scaramuzza, *Introduction to Autonomous Mobile
Robots*, 2nd ed. Cambridge, MA, USA: MIT Press, 2011. **⚠ verify edition** — *general
support for AMR vs. AGV navigation, wheel kinematics, dead reckoning.*

[7] A. Gfrerrer, "Geometry and kinematics of the Mecanum wheel," *Computer Aided Geometric
Design*, vol. 25, no. 9, pp. 784–791, Dec. 2008. **⚠ verify** — *the standard analytical
treatment of mecanum roller geometry; supports the omnidirectional-motion claim in §II.C.1.*

---

## B. Drivetrain and mechanical modelling (§III.A, §III.B)

[8] T. D. Gillespie, *Fundamentals of Vehicle Dynamics*. Warrendale, PA, USA: Society of
Automotive Engineers, 1992. **⚠ verify** — *source for the µ = 0.015 rolling-resistance
coefficient. At present that figure appears in §III.A with no citation at all, which is
the most exposed number in the mechanical section.*

[9] R. G. Budynas and J. K. Nisbett, *Shigley's Mechanical Engineering Design*, 11th ed.
New York, NY, USA: McGraw-Hill Education, 2020. **⚠ verify edition** — *bolted-joint shear
capacity and safety-factor practice, for Tables 3 and 4.*

[10] R. C. Hibbeler, *Mechanics of Materials*, 10th ed. Hoboken, NJ, USA: Pearson, 2017.
**⚠ verify edition** — *classical beam theory for the chassis deflection model in the
abstract and §III.B.*

[11] ASM International, "Aluminum 6061-T6; 6061-T651," *ASM Aerospace Specification Metals
Handbook*. [Online]. Available: https://asm.matweb.com [Accessed: Aug. 21, 2026].
**⚠ verify the exact page** — *source for the 207 MPa shear strength used in the Phase 3
clamp calculation.*

[12] Gates Corporation, *Design Manual: Synchronous Belt Drives*, Gates Corp., Denver, CO,
USA. [Online]. Available: https://www.gates.com [Accessed: Aug. 21, 2026].
**⚠ verify** — *HTD 3M belt working-tension figure in §III.B. Note the paper's Table 4
labels this row "GT2 belt" while the text says HTD3M — pick one and cite accordingly.*

---

## C. Electronics and power (§II.C.3, §III.A) — your section

[13] Espressif Systems, *ESP32-S3 Series Datasheet*, v1.6, Espressif Systems (Shanghai)
Co., Ltd., 2024. [Online]. Available:
https://www.espressif.com/sites/default/files/documentation/esp32-s3_datasheet_en.pdf
[Accessed: Aug. 21, 2026]. **⚠ verify version number**

[14] Espressif Systems, "ESP-NOW," *ESP-IDF Programming Guide*. [Online]. Available:
https://docs.espressif.com/projects/esp-idf/en/latest/esp32s3/api-reference/network/esp_now.html
[Accessed: Aug. 21, 2026]. **⚠ verify** — *supports the inter-controller link description
and the 250-byte payload / channel constraints.*

[15] *BLD-120A Brushless DC Motor Controller Specification*, manufacturer datasheet.
**✓ in your possession** — `docs/BLDC-BLD120A-bldc-motor-controller-specs.pdf`. *Cite this
one, not `BLD-120-English-version.pdf`: the two disagree on PWM input range and the
BLD-120A-specific sheet is the one your 2 kHz figure follows.*

[16] *80 mm Flange Brushless DC Gearmotor Specification*, supplier datasheet.
**✓ in your possession** — `docs/hardware/img/motor-80-flange-spec-table.jpeg`. *Source for
120 W, 5 A rated, 0.4 N·m base torque, 15:1 ratio.*

[17] STMicroelectronics, *VL53L0X: World's Smallest Time-of-Flight Ranging and Gesture
Detection Sensor*, DS11555, STMicroelectronics, 2018. [Online]. Available:
https://www.st.com/resource/en/datasheet/vl53l0x.pdf [Accessed: Aug. 21, 2026].
**⚠ verify document number**

[18] CEVA, Inc., *BNO08X Datasheet*, CEVA/Hillcrest Laboratories. [Online]. Available:
https://www.ceva-ip.com [Accessed: Aug. 21, 2026]. **⚠ verify** — *the BNO085 sensor-fusion
IMU; the datasheet is published under the BNO08X family name.*

[19] Allegro MicroSystems, *ACS758: Thermally Enhanced, Fully Integrated, Hall-Effect-Based
Linear Current Sensor IC*, Allegro MicroSystems, LLC. [Online]. Available:
https://www.allegromicro.com [Accessed: Aug. 21, 2026]. **⚠ verify** — *supports the
26.4 mV/A ratiometric sensitivity and ±50 A range in your sensor-selection argument.*

[20] Texas Instruments, *ADS111x Ultra-Small, Low-Power, I2C-Compatible, 860-SPS,
16-Bit ADCs with Internal Reference, Oscillator, and Programmable Comparator*, SBAS444,
Texas Instruments Inc. [Online]. Available: https://www.ti.com/lit/ds/symlink/ads1115.pdf
[Accessed: Aug. 21, 2026]. **⚠ verify document number**

[21] NXP Semiconductors, *PCA9685: 16-channel, 12-bit PWM Fm+ I2C-bus LED controller*,
Rev. 4, NXP Semiconductors N.V., 2015. [Online]. Available:
https://www.nxp.com/docs/en/data-sheet/PCA9685.pdf [Accessed: Aug. 21, 2026].
**⚠ verify revision**

[22] Infineon Technologies, *BTN7960B/BTS7960B High Current PN Half Bridge NovalithIC™*,
Infineon Technologies AG. [Online]. Available: https://www.infineon.com
[Accessed: Aug. 21, 2026]. **⚠ verify** — *the 43 A H-bridge modules on the arm board.*

[23] onsemi, *2N3904 General Purpose Transistor NPN Silicon*, Rev. 12, onsemi.
[Online]. Available: https://www.onsemi.com/pdf/datasheet/2n3904-d.pdf
[Accessed: Aug. 21, 2026]. **⚠ verify revision** — *supports the saturation calculation
for the Driver PCB open-collector stage (Appendix C).*

[24] NXP Semiconductors, *I2C-bus specification and user manual*, UM10204, Rev. 7, NXP
Semiconductors N.V., 2021. [Online]. Available:
https://www.nxp.com/docs/en/user-guide/UM10204.pdf [Accessed: Aug. 21, 2026].
**⚠ verify revision** — *cite where you describe XSHUT address reassignment on a shared bus.*

[25] Littelfuse, Inc., *Fuseology Selection Guide*, Littelfuse, Inc., Chicago, IL, USA.
[Online]. Available: https://www.littelfuse.com [Accessed: Aug. 21, 2026].
**⚠ verify** — *this is the citation that turns your fuse table from assertion into method:
the 1.5× continuous-current rule and, importantly, the time-delay vs. fast-acting
distinction that the four 10 A driver fuses depend on.*

[26] Low-voltage electrical installations — Part 5-52: Selection and erection of electrical
equipment — Wiring systems, IEC 60364-5-52:2009, International Electrotechnical
Commission, Geneva, Switzerland, 2009. **⚠ verify** — *conductor ampacity and derating,
for the pack-conductor gauge row of Table 6. Singapore's SS 638 derives from BS 7671,
which follows this; cite whichever your library gives you access to.*

[27] T. L. Bergman and A. S. Lavine, *Fundamentals of Heat and Mass Transfer*, 8th ed.
Hoboken, NJ, USA: Wiley, 2017. **⚠ verify edition** — *natural-convection correlations
behind the "15–25 W in still air" claim in the thermal paragraph, which is currently
uncited.*

[28] Secondary cells and batteries containing alkaline or other non-acid electrolytes —
Safety requirements for portable sealed secondary lithium cells, and for batteries made
from them, for use in portable applications — Part 2: Lithium systems, IEC 62133-2:2017,
International Electrotechnical Commission, Geneva, Switzerland, 2017. **⚠ verify** —
*optional, but it gives you something to point at in §V when you note the custom pack has
no documented ratings.*

---

## D. Where each reference belongs in the text

| Claim currently uncited | Cite |
|---|---|
| AMR market growth (§I) | [1] |
| "Flexley Mover P603 … Seagrid S7" (§I) | [2], [3] — and fix both names |
| Mecanum omnidirectional capability (§I, §II.C.1) | [4], [7] |
| AMR vs. AGV distinction (§I) | [6] |
| µ = 0.015 rolling resistance (§III.A) | [8] |
| Gearbox efficiency η = 0.88 "2-stage planetary estimate" (§III.A) | [16] if the datasheet states it; otherwise label it an assumption, not a spec |
| 0.38 / 0.4 N·m rated torque, 120 W (§III.A) | [16] |
| Motor natural convection 15–25 W (§III.A) | [27] |
| 6061-T6 shear strength 207 MPa (§III.B) | [11] |
| M4 grade 8.8 bolt shear capacity (§III.B) | [9] |
| HTD3M belt working tension 60 N (§III.B) | [12] |
| PWM 1–3 kHz, 2–90 % duty, P-sv range (§II.C.3) | [15] |
| ToF sensing and XSHUT re-addressing (§II.C.3) | [17], [24] |
| Current-sensor selection argument (§II.C.3) | [19], [20] |
| ESP-NOW link (§II.C.3) | [13], [14] |
| Fuse sizing rule and time-delay requirement (§III.A, Table 6) | [25] |
| Conductor gauge (Table 6) | [26] |
| Safety limitations, E-stop discussion (§V) | [5] |

---

## E. Two corrections the reference hunt turned up

1. **The Flexley Mover P603 is an ABB product**, and it meets ISO 3691-4 with a 1500 kg
   payload and ±5 mm positioning. Your §I uses it as an example of a platform that
   "cannot fit under a trolley" — that is a fair claim about form factor, but state the
   manufacturer and give the payload, or a reader familiar with the product will read the
   sentence as vague.
2. **"Seagrid" is Seegrid**, and the product is the Palion Tow Tractor S7. A misspelled
   competitor name in the first page of a report is a cheap thing to lose credibility on.

## F. What is still missing

The strongest citation you do not yet have is a **peer-reviewed AMR docking or
trolley-coupling paper** — something that places your clamp-and-tow approach in the
literature rather than presenting it as invented from nothing. Search IEEE Xplore for
"autonomous cart docking", "AGV automatic hitching", and "under-cart AMR coupling"
through the SUTD library; one or two results there would strengthen §I and §V more than
any additional datasheet.

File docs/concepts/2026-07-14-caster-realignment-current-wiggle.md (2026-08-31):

# Concept: Current-Sensed Caster Re-Alignment ("detect-and-wiggle")

**Status:** PARKED CONCEPT — not scheduled, not designed against the codebase yet.
**Date:** 2026-07-14
**Related:** [caster load mechanics report](../research/2026-07-13-caster-load-mechanics.md)

## Problem it addresses

A trolley on 4 swivel casters resists motion most when its casters are **misaligned** (pointing across the intended travel direction after a stop or reversal). Reorienting a *static* caster costs ~10× the force of a *rolling* one, producing a startup spike of roughly **150–260 N for a 200 kg load** (~10–13 % of load weight). This spike, not steady rolling, is what defeats a light pusher.

## The idea

1. **Detect** elevated resistance via **drive-motor current sensing** (misaligned caster → higher resistance → higher current). Mirrors the existing clamp stall-current pattern (`kClampStallAmps`).
2. **Correct** by superimposing a small **yaw/lateral "wiggle"** on forward creep — keep the casters micro-rolling so they reorient in the cheap rolling regime instead of static scrub. Because the robot clamps under the trolley *centre* and the casters are at the corners, small yaw gives the caster pivots real velocity (`v = ω × r`), so the leverage is favourable.
3. **Confirm** alignment when current drops back to the rolling baseline, then resume straight travel.

## Why it works (physics)

- Rolling reorientation ≈ **1/10th** the force of static scrub (relaxation-length behaviour).
- Never letting the system go fully static avoids the breakaway/misaligned-start spike entirely.
- Confirmed by the ergonomics literature: reversed/misaligned caster starts measurably raise initial push force, worse for larger casters (IEEE IEEM 2015; ScienceDirect S0003687002000029).

## CRITICAL caveat — complement, not substitute

This addresses the **caster-flip** problem, **not the traction ceiling**. If the robot is traction-limited (light robot, no weight transfer, 100–200 kg load), the wheels **slip before** the current signal is actionable — and on slip, mecanum current *falls*, so current sensing detects "already stuck," not "about to stick." **Order of operations:** first ensure adequate traction (robot mass and/or weight transfer / lift — see the mechanics report), *then* detect-and-wiggle earns its keep as a caster-flip handler. It cannot rescue a traction deficit.

## Where it sits among alternatives (cheapest → most robust)

- **Open-loop back-up jog** (reverse 50–100 mm before a stroke): aligns all casters proactively, no sensing, no mid-stroke disturbance. Do this first.
- **This concept (detect-and-wiggle):** the closed-loop *reactive* fallback for a caster that stalls mid-path (e.g. right after a turn) despite the jog.
- **Lift the casters:** unloaded casters self-home — removes the problem entirely (Amazon/Kiva patent US 12,472,772).

Recommended layering: **jog proactively → wiggle reactively → all gated on having the traction to actuate either.**

## Sensing requirements (resolved 2026-07-14)

- **Detection:** drive-motor **current sense** only — no shaft position needed.
- **Wiggle execution:** small current-gated dither; needs at most coarse speed feedback.
- **Speed feedback:** use existing **BLDC hall sensors** + the **BLD120A `FG` output**; apply **period-measurement (time between hall edges)** to keep resolution usable at the low creep speeds where the wiggle runs.
- **Heading / drift correction:** add an **IMU** — for a mecanum robot dragging ~100 kg, wheel odometry is corrupted by roller/load slip and an IMU is the right heading source.
  - **Recommended part (2026-07-15, not yet purchased):** a modern **6-axis** gyro/accel — *not* a 9-axis. The magnetometer that would give absolute heading is unreliable inches from 4 BLDC motors (switching currents + steel swamp Earth's tiny field), so a 9-axis buys a mag axis you can't trust.
  - **Architecture:** gyro for smooth short-term yaw (holds heading through a maneuver) **+ the dock ToF as the periodic absolute correction**. That makes the mag redundant.
  - **AliExpress candidates:** **ICM-42688-P** (~$5, low-noise gyro — best value pick); **MPU6050** (~$1.50, drifts over minutes but fine to prototype); or **BNO085 in UART-RVC mode** (~$12–20, on-chip fusion streams yaw/pitch/roll → zero fusion code). Watch counterfeits on MPU6050/9250 boards.
  - **Placement matters more than the chip:** mount far from motors/high-current wiring, near the rotation centre, on foam/rubber for vibration damping.
- ~~**Encoders (AS5600) — DEFERRED.**~~ **ABANDONED.** Written as deferred; they were never made to work and the project shipped without wheel-speed feedback of any kind. The AS5600 boards and shaft magnets are **still physically mounted on the motors**, unwired and absent from the firmware. Two board-level faults killed them — see [`docs/hardware/boards.md`](../hardware/boards.md) §1. The TCA9548A mux route suggested below went with them; if anyone revisits wheel-speed feedback, **the motors' own hall sensors land on the drivers' screw terminals** and are the cheaper route ([`docs/hardware/components.md`](../hardware/components.md) §2).

## Open questions / next steps to prototype

1. Bench-measure the actual current signature of a deliberately-misaligned caster vs baseline — does it clear the mecanum roller-hand-off noise floor?
2. Verify traction margin exists first (robot mass / weight transfer) so the signal is actionable.
3. Tune wiggle amplitude/frequency for reliable alignment with minimum load/odometry disturbance.
4. Decide the detect→wiggle→confirm loop as a state added to / gated by `DockingStateMachine` + `SafetyMonitor`.
5. Regardless of this concept: current sensing has standing value as a **slip/jam/obstacle monitor** feeding `SafetyMonitor`.

*When promoted from concept to feature: run a proper brainstorm and graphify-ground it against the existing `DockingStateMachine` / `SafetyMonitor` structure before implementing.*

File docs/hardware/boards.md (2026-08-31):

# The three PCBs — connector reference

Every table here was extracted from the KiCad netlists, not from a rendered
schematic and not from `pins.h`. Where firmware disagrees with the netlist, the
disagreement is called out rather than smoothed over.

| Board | Size | KiCad project | Job |
|---|---|---|---|
| **Wheel Drive PCB** | 130 × 105 mm | `KiCad/Wheel Drive PCB/` | base ESP + 4 motor drivers + all base sensors |
| **Driver PCB** ×4 | 42.8 × 33.8 mm | `KiCad/Driver PCB/` | 3.3 V → open-collector adapter, one per motor |
| **Arm Subsystem PCB** | 110 × 110 mm | `KiCad/Arm Subsystem PCB/` | arm ESP + 2 H-bridges + 4 servos + 8 limit switches |

Schematic / layout / 3D-view renders for every board (including the historical
PCA9548A breakout) are indexed in [`KiCad/README.md`](../../KiCad/README.md#board-renders).

The Arm Subsystem PCB is **by Kai Xiang and Heng Li, EPD Batch of 2028**, as is
the `arm/` firmware.

---

## How to read a connector on these boards

The silkscreen is better than the older docs imply. **Every pin is functionally
labelled** — `FL SV`, `XSHUT FL`, `A0`, `Encoder FL`, `3V3`, `GND`. You never
have to infer a corner from a J-number; read the label next to the pin.

Two things the silkscreen does *not* tell you, which is what the tables below
are for:

1. **Which GPIO** is behind a labelled pin.
2. **Pin 1.** It is the square pad. On a 1×N header every other pad is round.

---

## 1. Wheel Drive PCB

**U6** is an ESP32-S3-DevKitC-1 **N16R8**. **Socket it** — 2× 1×22 female
header — do not solder the DevKit down. It is the most likely part to need
swapping and the most expensive to destroy getting off.

### J4 / J5 / J6 / J7 — BLDC driver outputs

One per wheel. These go to the **Driver PCB**, never straight to a BLD-120A.

| Pin | Signal | FL (J4) | FR (J5) | RL (J6) | RR (J7) |
|---|---|---|---|---|---|
| 1 | BRK | GPIO39 | GPIO38 | GPIO15 | GPIO13 |
| 2 | EN | GPIO40 | GPIO48 | GPIO16 | GPIO12 |
| 3 | F/R | GPIO41 | GPIO47 | GPIO17 | GPIO11 |
| 4 | GND / COM | — | — | — | — |
| 5 | SV | GPIO42 | GPIO21 | GPIO18 | GPIO10 |

**EN and BRK are per-wheel, not ganged.** Each wheel can be shut down
independently. `hardware-architecture.md` §9 still lists "main.cpp passes one
shared EN/BRK pair to all four motors" as an open item — check that before
trusting per-wheel shutdown.

> ⚠️ **GPIO48 is also the DevKitC's onboard RGB LED.** Driving a WS2812 frame on
> it fires an 800 kHz burst into the FR motor's ENABLE — and because the adapter
> inverts, HIGH is *asserted*. Never use the onboard LED on this board.

### TOF5 / TOF6 / TOF7 / TOF8 — VL53L0X time-of-flight

| Pin | Signal | FL (TOF5) | FR (TOF6) | RL (TOF7) | RR (TOF8) |
|---|---|---|---|---|---|
| 1 | VIN | 3V3 | 3V3 | 3V3 | 3V3 |
| 2 | GND | — | — | — | — |
| 3 | SCL | GPIO9 | ← shared | ← | ← |
| 4 | SDA | GPIO8 | ← shared | ← | ← |
| 5 | GPIO (module interrupt) | **not connected** | | | |
| 6 | **XSHUT** | GPIO4 | GPIO5 | GPIO6 | GPIO7 |

All four sensors are `0x29` from the factory. They are brought up one at a time
via XSHUT and re-addressed — that is what `lib/hal_esp32/Vl53l0xArray.h` does. No
mux involved.

The breakout **must** break out XSHUT. A VL53L0X module without an XSHUT pin
cannot be used here.

> **Correcting `gotchas.md` §9.** That entry warns the ToF connectors are
> "labelled 4, 6, 7, 8" and that only the first label matches its pin. The
> reference designators are **TOF5–TOF8**, and the functional silkscreen beside
> pin 6 reads `XSHUT FL` / `XSHUT FR` / `XSHUT RL` / `XSHUT RR`. Corner identity
> on the board is unambiguous. **[VERIFIED — netlist + silkscreen extraction]**

### J8 — ADS1115 current-sense ADC

| Pin | 1 | 2 | 3 | 4 | 5 | 6 | 7 | 8 | 9 | 10 |
|---|---|---|---|---|---|---|---|---|---|---|
| Signal | 3V3 | GND | SCL | SDA | **GND** | NC | A0 | A1 | A2 | A3 |

Pin 5 lands on the module's **ADDR** pin and the board ties it to ground, so the
**ADS1115 address is `0x48`, fixed in copper.** `hardware-architecture.md` §9
lists "set ADS1115 ADDR→GND for 0x48" as an open to-do — it is already done, and
there is no jumper to get wrong. **[VERIFIED — netlist]**

Pin 6 is the module's ALRT output, deliberately unconnected.

### J9 / J12 / J14 / J17 — ACS758 current sensors

| Pin | Signal | J9 | J12 | J14 | J17 |
|---|---|---|---|---|---|
| 1 | VCC | **3V3** | 3V3 | 3V3 | 3V3 |
| 2 | GND | — | — | — | — |
| 3 | — | not connected | | | |
| 4 | OUT | **A0** | **A1** | **A2** | **A3** |
| | schematic name | **FL** | **FR** | **RL** | **RR** |

Two corrections here, both worth making before someone re-derives them:

> **The sensors run on 3.3 V.** `hardware-architecture.md` §6 leaves "confirm the
> rail before wiring" open — pin 1 of all four connectors is on the `/3V Wheel`
> net. The ACS758 is ratiometric, so at 3.3 V a `-050B` gives 26.4 mV/A around a
> 1.65 V zero, read directly by the 3.3 V ADS1115. **No divider, no level
> shifting.** Powering it at 5 V instead would put up to 5 V into a 3.3 V ADC
> input. **[VERIFIED — netlist]**

> **`pins.h`'s connector table is inverted, and `gotchas.md` §9 draws the wrong
> lesson from it.** `pins.h` comments claim `J14, J17, J12, J9` = FL, FR, RL, RR
> and §9 concludes "never infer a channel from a J-number ... not numeric order."
> The netlist says the connectors *are* in order: **J9=FL=A0, J12=FR=A1,
> J14=RL=A2, J17=RR=A3.** The **code is correct** — `kCurrentAdsChannel =
> {0,1,2,3}` for FL..RR matches the schematic. Only the explanatory comment is
> wrong. **[VERIFIED — netlist]**
>
> Note that `pcb_identify.cpp`, cited as the empirical authority, identifies a
> corner by watching an encoder *and* a current channel move together. Half that
> procedure died with the encoders, so the tool can no longer self-verify a
> corner. Read the `A0`–`A3` silkscreen instead.

### J19 — BNO085 IMU

| Pin | 1 | 2 | 3 | 4 | 5–10 |
|---|---|---|---|---|---|
| Signal | 3V3 | GND | SCL | SDA | not connected |

> ⚠️ **Check the module pinout before plugging this in.** The board provides a
> generic 10-pin header with only four pins live, in the order 3V3 · GND · SCL ·
> SDA. Several common BNO085 breakouts (the Adafruit BNO08x among them) run
> **VIN · 3Vo · GND · …**, where the module's pin 2 is a regulator *output*.
> Landing that on the board's GND pin shorts the module's 3.3 V regulator to
> ground. **[HYPOTHESIS — the netlist records only "Pin_2", so the intended
> module is not captured anywhere in the project.]** *Check: compare the module's
> own silkscreen against the four labels on J19 before it goes in. If they do not
> line up 1:1, wire it with flying leads, not by seating it on the header.*

### J1 / J11 / J15 / J18 and J2 / J10 / J13 / J16 — encoders (dead)

The AS5600 encoders were abandoned 2026-08-13. The headers remain.

| 1×04 (J1, J11, J15, J18) | 1 | 2 | 3 | 4 |
|---|---|---|---|---|
| Signal | **not connected** | SDA | SCL | GND |

| 1×03 (J2, J10, J13, J16) | 1 | 2 | 3 |
|---|---|---|---|
| Signal | 3V3 | OUT | GND |
| FL (J2) → GPIO1 · FR (J10) → GPIO2 · RL (J13) → GPIO3 · RR (J16) → GPIO14 | | | |

> **Why they could never work, from the netlist.** Two independent board-level
> faults:
>
> 1. **Pin 1 of every 1×04 connector is unconnected — the I²C-side header has no
>    VCC.** `hardware-architecture.md` §5 blames "a missing VCC connection in the
>    loom". It is in the PCB. That is exactly the parasitic-power signature that
>    was observed. **[VERIFIED — netlist]**
> 2. All four AS5600 share `0x36` with no address pin, and the board **commons
>    SDA/SCL across all four**. As built they cannot be addressed individually;
>    isolating them needs eight trace cuts.
>
> Bryan's later attempt used a PCA9548-type I²C mux externally; it overheated and
> failed with more than two sensors attached. **[OBSERVED — Bryan]**
>
> If anything reclaims GPIO1/2/3/14, remember they are still routed to these
> headers. An AS5600's `OUT` is an actively driven analog output and will fight
> whatever else is on the net. **Unplug the encoder looms rather than trusting
> the pins are free.**

### J3 — Common Ground

| Pin | 1 | 2 |
|---|---|---|
| Signal | board ground | **not connected** |

Ground bond only — **not** a power input. This is the single most important
connection on the board; see `startup.md` §2.

### Pins the board deliberately leaves alone

`GPIO0 · 19 · 20 · 26–37 · 43 · 44 · 45 · 46`, plus the DevKit's `5V` and
`CHIP_PU` pads. **[VERIFIED — netlist]** 26–37 are flash and octal PSRAM;
19/20 are native USB; 0/45/46 are strapping.

Genuinely free: **GPIO43 and GPIO44** — but only in a build whose console is
native USB-CDC. `bench_ble` is not one, so the IDF console sits on UART0 =
GPIO43/44.

---

## 2. Driver PCB — the 3.3 V → 5 V adapter

**You need four.** One channel-set per board.

This is the transistor adapter from `hardware-architecture.md` §4, fabricated.
Reconstructed from `DriverPCB.dsn`:

```
J1 "ESP"                                              J2 "BLD-120A"
 pin 1 BRK ──10k(R1)──┬── B  Q1 ── C ────────────────► pin 1 BRK
                   100k(R6)      E ──┐
 pin 2 EN  ──10k(R2)──┬── B  Q2 ── C ─┼──────────────► pin 2 EN
                   100k(R5)      E ──┤
 pin 3 F/R ──10k(R3)──┬── B  Q3 ── C ─┼──────────────► pin 3 F/R
                   100k(R4)      E ──┤
                        └────────────┤
 pin 4 COM ─────────────────────────┴───────────────► pin 4 COM
 pin 5 SV  ──────────1.5k(R7)───────────────────────► pin 5 SV
```

| Ref | Value | Job |
|---|---|---|
| Q1, Q2, Q3 | **2N3904** (TO-92) | open-collector switch, one per control line |
| R1, R2, R3 | 10 kΩ | base series |
| R4, R5, R6 | 100 kΩ | **base-to-COM pulldown — critical** |
| R7 | 1.5 kΩ | SV series (manual asks for 1–10 kΩ) |

**Why the 100 kΩ matters:** it holds the transistor off while the GPIO is
high-impedance — at boot, in reset, or unplugged. Without it the driver inputs
float and the motor state at power-up is undefined. This is what makes the
power-up behaviour in `startup.md` §1 safe.

**The transistor inverts every control line.** Firmware handles this with the
single switch `fal::kControlViaMosfet` in `Bld120aMotor.h`, which derives all four
polarity constants and is checked by `static_assert`. Do not invert a second time
in application code.

> ⚠️ **Do not substitute a BC547.** The footprint is `TO-92_Inline_Wide_**EBC**`
> and the symbol is a 2N3904 (**E-B-C**). **BC547 is C-B-E** — same package,
> mirrored pinout. Dropped into these holes unrotated it swaps collector and
> emitter and reproduces exactly the fault that `hardware-architecture.md` §4
> records as costing an evening. `hardware-architecture.md` §4 currently says
> "BC547 **or** 2N3904"; on this PCB that is only true if you rotate the BC547
> 180°. **[VERIFIED — footprint + symbol]**

### Diagnosing a dead channel

From the failure that cost that evening — these are the two measurements that
localise it in under a minute:

| Measurement | Healthy | Faulty (what was seen) |
|---|---|---|
| base → COM, GPIO driven high | **~0.7 V** (junction clamps) | 1.678 V — junction not conducting |
| collector → COM, enabled vs disabled | large change | 1.069 → 0.945 V — barely moves |

A base that will not clamp at ~0.7 V means the B–E path to COM is broken. A
collector that does not move between states means the transistor is not
switching. Currents are microamps throughout — you cannot damage anything by
probing.

### Intermittent channels — clean between the traces

**[OBSERVED — Bryan]** A channel that works, then does not, then does again is
usually **flux residue** between the traces rather than a component fault. Old
no-clean flux absorbs moisture and oxidises, and the leakage across a 200 µm gap
is enough to matter at the microamp currents this board runs at.

Isopropyl alcohol and a stiff brush between the traces, dried thoroughly. Do this
**before** replacing parts — it is the cheaper hypothesis and it is usually
right.

---

## 3. Arm Subsystem PCB

**U1** is a second ESP32-S3-DevKitC-1 N16R8. Board is 110 × 110 mm, 2-layer.

Firmware: `arm/` (vendored — see `arm/LOCAL-CHANGES.md`).

### J1 / J2 — BTS7960 H-bridge, X and Y extension motors

| Pin | Signal | X (J1) | Y (J2) |
|---|---|---|---|
| 1 | +5V | — | — |
| 2 | GND | — | — |
| 3 | L_EN | GPIO7 | GPIO41 |
| 4 | R_EN | GPIO15 | GPIO40 |
| 5 | LPWM | GPIO16 | GPIO39 |
| 6 | RPWM | GPIO17 | GPIO38 |

Matches `arm/src/HardwareConfig.h` exactly. **[VERIFIED]**

The 12 V motor supply goes to the **BTS7960's own B+/B− screw terminals**, not
through this PCB. This header carries logic only.

### S1 / S2 / S3 / S4 — servo headers

| Pin | 1 | 2 | 3 |
|---|---|---|---|
| Signal | signal | +5V | GND |

| Header | Schematic name | Signal pin |
|---|---|---|
| S1 | Servo X1 | GPIO10 |
| S2 | Servo X2 | GPIO47 |
| S3 | Servo Y1 | GPIO4 |
| S4 | Servo Y2 | GPIO14 |

> ⚠️ **These four headers are not used by the shipped firmware.**
> `arm/src/MotorController.h` drives all four servos through an
> `Adafruit_PWMServoDriver` — a **PCA9685 at `0x40` over I²C**, channels 0–3.
> GPIO10, 47, 4 and 14 are never referenced anywhere in `arm/src/`.
>
> There is **no PCA9685 footprint or connector on this board.** The only I²C
> access points are the four ToF headers.
>
> **[VERIFIED — netlist has no PCA9685; `grep -rn "PCA9685\|setPWM" arm/src/`
> shows the firmware talks only to the breakout.]**
>
> **As actually built [OBSERVED — Bryan, 2026-08-16]:** a PCA9685 is fitted and
> **plugged into one of the ToF headers** to reach I²C, with the servos on its own
> outputs. `S1`–`S4` are dead copper. The displaced ToF sensor is chained through
> the breakout, so **the arm's I²C is a hand-built daisy chain, not the star this
> board draws.** Trace it physically before trusting any bus diagram — including
> the one in `hardware-architecture.md`.
>
> The mismatch is between the board and the firmware, not a defect in either.
> Two ways of closing it: respin the board with a PCA9685 header, or rewrite
> `MotorController` to use four LEDC channels on the pins already routed. The
> second needs no new hardware, frees the I²C bus, and returns the fourth ToF
> sensor to its own header.

### SW1–SW8 — limit switches

Two-pin headers: **pin 1 = signal, pin 2 = GND.** Plain switch-to-ground; there
are no pull-up resistors on the board, and the firmware sets `INPUT_PULLUP` on
all eight. **Pressed reads LOW.**

| Header | Schematic name | Firmware name | GPIO |
|---|---|---|---|
| SW3 | X Limit Max | `X_ARM_MAX` | **GPIO42** |
| SW7 | X Limit Min | `X_ARM_MIN` | GPIO2 |
| SW8 | Y Limit Max | `Y_ARM_MAX` | GPIO1 |
| SW6 | Y Limit Min | `Y_ARM_MIN` | GPIO3 |
| SW1 | Limit Switch X1 | `LIMIT_X1` | GPIO11 |
| SW4 | Limit Switch X2 | `LIMIT_X2` | GPIO48 |
| SW2 | Limit Switch Y1 | `LIMIT_Y1` | GPIO5 |
| SW5 | Limit Switch Y2 | `LIMIT_Y2` | GPIO13 |

All eight match `arm/src/LimitSwitches.h` exactly. **[VERIFIED]**

> ### This kills one hypothesis in `gotchas.md` Open Issue A
>
> Open Issue A is "X-axis extend does not stop at its limit switch", and its
> leading hypothesis was **"`X_ARM_MAX` on GPIO42 is not wired, or is wired to a
> different input."**
>
> **The netlist rules that out.** SW3 "X Limit Max" connects to GPIO42 and to
> ground, the firmware reads GPIO42 with `INPUT_PULLUP`, and pressed = LOW. The
> PCB is correct and the firmware matches it. **[VERIFIED]**
>
> What survives, re-ranked:
>
> 1. **No switch is physically fitted at SW3**, or it is fitted but the mechanism
>    stops before reaching it. Nothing in the electrical design would show this.
> 2. **A loom fault** between the SW3 header and the switch — open wire, bad
>    crimp, connector off by one.
> 3. GPIO42 compromised as an input. Still speculative, and now less likely: the
>    *base* board drives GPIO42 as FL SV and it works.
>
> The 30-second experiment is unchanged and still nobody has run it: connect the
> arm over USB (`cd arm && pio device monitor -e esp32s3`), press `m` for the live
> switch monitor, and press the X max stop by hand. **Note the arm's `Serial` is
> UART0 on GPIO43/44, not native USB** — plugging into the USB-C port gives a port
> that enumerates, stays silent and ignores you (`gotchas.md` §6).

### TOF1–TOF4 — VL53L0X, arm side

Same 6-pin pinout as the base board (VIN · GND · SCL · SDA · NC · XSHUT).

| Header | Schematic name | XSHUT GPIO | Assigned address |
|---|---|---|---|
| TOF1 | ToF X1 | GPIO18 | `0x30` |
| TOF3 | ToF X2 | GPIO21 | `0x31` |
| TOF2 | ToF Y1 | GPIO6 | `0x32` |
| TOF4 | ToF Y2 | GPIO12 | `0x33` |

Matches `HardwareConfig.h`. **[VERIFIED]** Note the designator order is *not* the
axis order — TOF2 is Y1 and TOF3 is X2.

> ⚠️ **A dead ToF here reads as "clear air."** `TofSensorArray.cpp` substitutes
> 8191 mm on `RangeStatus == 4`, and the air test is `distance > 200`. A
> disconnected or failed sensor therefore tells the arm it may stop extending and
> start flipping. `gotchas.md` §1. Do not debug arm motion without checking these
> first.

### J3 — External Buck 5V and GND

| Pin | 1 | 2 |
|---|---|---|
| Signal | **+5 V in** | GND |

Feeds all four servo headers and both BTS7960 logic supplies. **Unlike the Wheel
Drive PCB's J3, this one is a power input.** See `startup.md` §2.

### Pins the arm board leaves unconnected

`GPIO0 · 19 · 20 · 35 · 36 · 37 · 43 · 44 · 45 · 46`, the DevKit `5V` pad, and
`CHIP_PU`. **[VERIFIED — netlist]**

Note GPIO3 **is** used (`Y_ARM_MIN`) and is an ESP32-S3 strapping pin (JTAG
source select). It is read at reset. A limit switch held closed at power-on pulls
it low — which is the strapping condition. Nothing has been observed to go wrong,
but if the arm ever boots strangely with the Y axis at its minimum stop, look
here first. **[HYPOTHESIS — pin function is verified, the interaction is not]**

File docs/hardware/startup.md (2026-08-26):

# Powering up Falali

**Read this before you connect the battery.** It is the only document that
describes the power system, because none of it is visible in the KiCad files —
no board in this project has a power input connector.

Tags follow `docs/gotchas.md`: **[VERIFIED]** measured or read from source,
**[OBSERVED]** it happened and the evidence is quoted, **[HYPOTHESIS]** a model
that fits and has not been tested. Where a hypothesis matters, the experiment
that would kill it is written next to it.

---

## 1. The safety facts, before anything else

### The big red button is not an emergency stop **[VERIFIED — Bryan, 2026-08-16]**

It looks like an E-stop. It is wired as an **enable**.

> **Pressing it turns the 12 V arm rail ON. Releasing it turns that rail OFF.**

Every reflex you have about mushroom buttons is backwards here. In an emergency,
the instinct is to slap the button down — on this machine that **energises** the
arm rather than killing it. To actually stop the arm you must **twist and pull
the button out.**

As wired, it is a power switch with a misleading head.

**What changing it would involve:** the fitted part is a **1NO 1NC DPST**
latching mushroom switch, so both contact types are physically present and the
**NC contact is currently unused**. The rail sits on NO. Moved to NC the
behaviour inverts to what most people expect — released (out) = rail live,
pressed (in) = rail dead — and nothing else in the system changes.

**What the button does not cover, either way:** the **24 V motor rail is not
switched by it at all.** A conventional E-stop would break 24 V too. The only
thing that stops the wheels is the firmware, and — see §5 — the firmware is not
running for the first part of the power-up.

### The wheels are free until the firmware boots **[VERIFIED — netlist + polarity table]**

This falls out of the Driver PCB's design and is worth internalising.

Each control line reaches the BLD-120A through a 2N3904 with a **100 kΩ
base-to-COM pulldown**. While the ESP is unpowered, in reset, or simply not yet
running your code, its GPIOs are high-impedance, the pulldown holds the
transistor **off**, and the collector is released. Released means the driver's
own internal pull-up wins. Cross-referencing the asserted-state table in
`hardware-architecture.md` §3:

| Line | Transistor off → driver pin | Meaning |
|---|---|---|
| EN | released (high) | **motor disabled** |
| BRK | released (high) | **brake released** |
| F/R | released (high) | forward |

So the safe half is real — an unbooted ESP cannot drive the motors. But the
brake is **also** released, so **the robot is a free-rolling 4-wheel trolley from
the moment 24 V comes up until firmware takes over.**

On a bench: wheels off the ground, or chocked. On the floor: on a level surface,
against nothing you mind it touching. Do not power up on a ramp.

**The arm behaves the opposite way.** Its extension motors are **self-locking
worm gearboxes**, so the arm holds position with no power at all and does not
back-drive under load. Cutting the 12 V rail freezes the arm where it is; it does
not drop. The flipper servos are not self-locking — `stopAll()` cuts their PWM
and releases them, so they settle wherever gravity takes them (`gotchas.md` §3).

### There is no motor fault detection in hardware **[VERIFIED]**

The BLD-120A exposes no ALM terminal — "RUN/ALM" is an LED, not an output, and
the Wheel Drive PCB has no ALARM net. Protection is, in order:

1. the driver's **P-sv** overload trim (set it to the motor's rated watts),
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

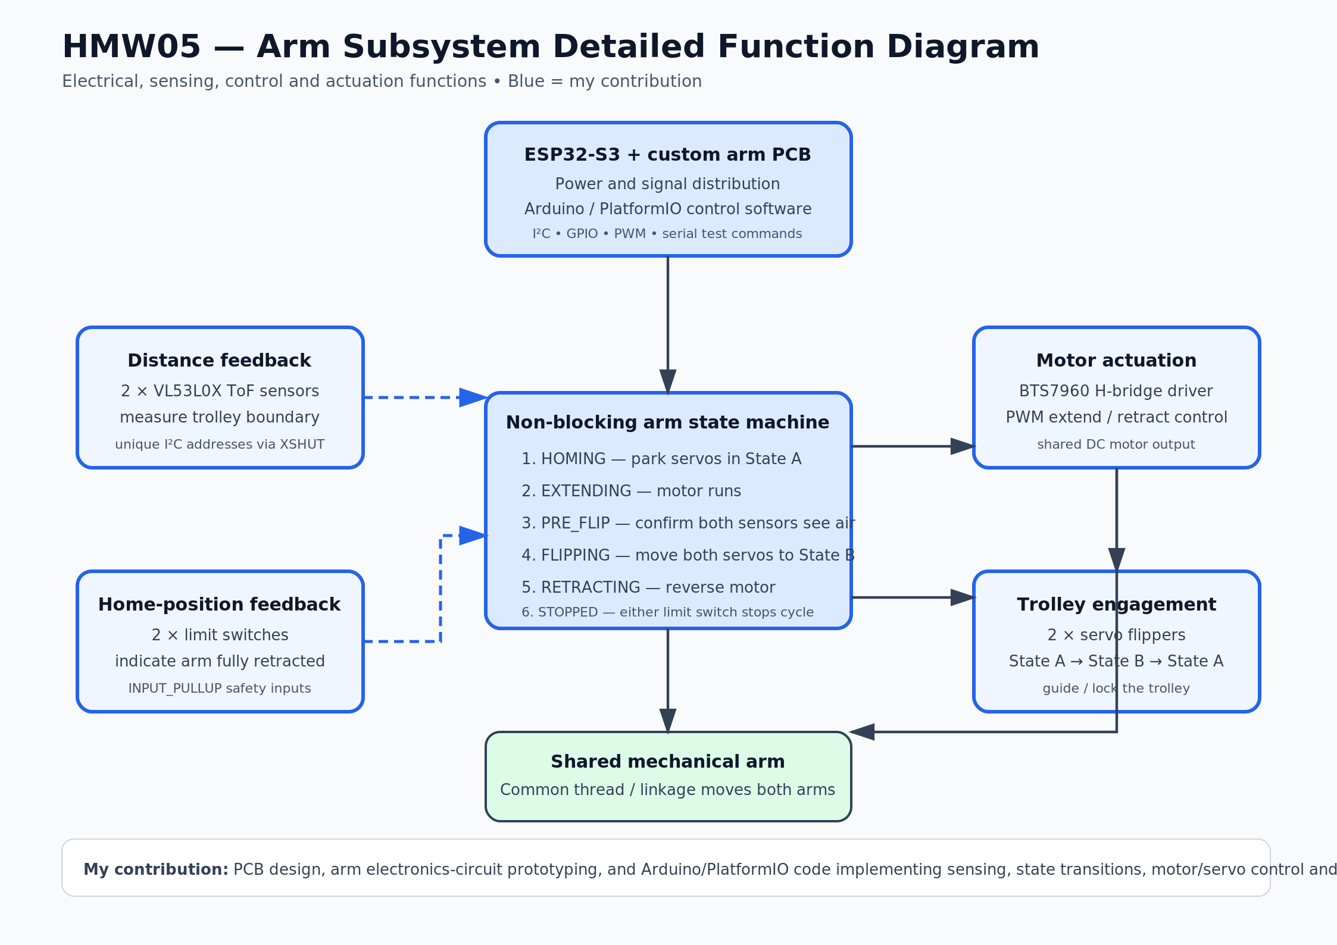
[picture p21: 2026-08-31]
docs/function-diagram-02-arm-subsystem.png

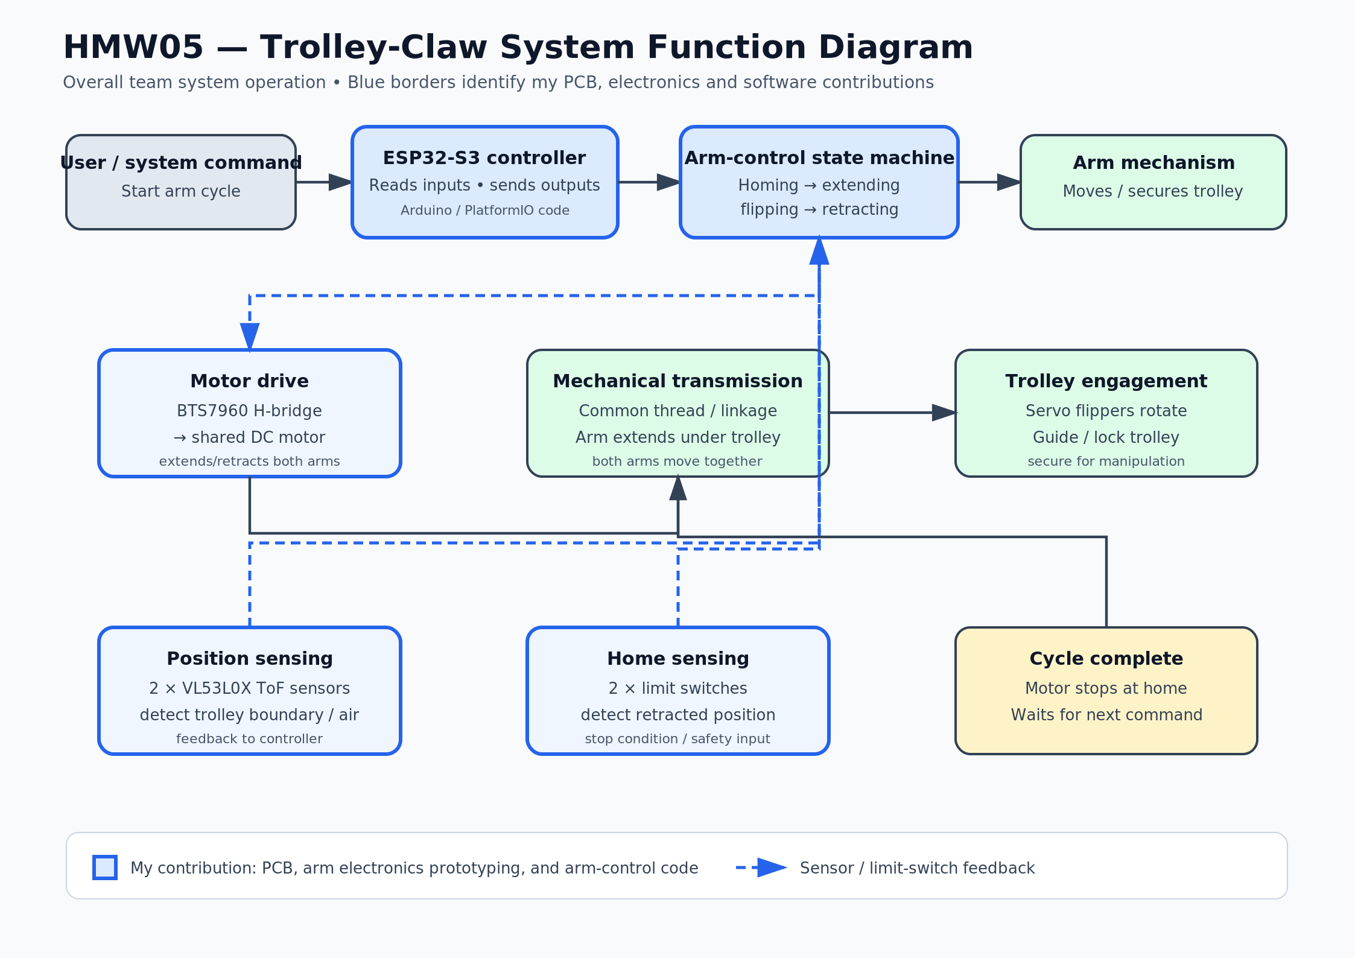
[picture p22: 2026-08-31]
docs/function-diagram-01-system-flow.png

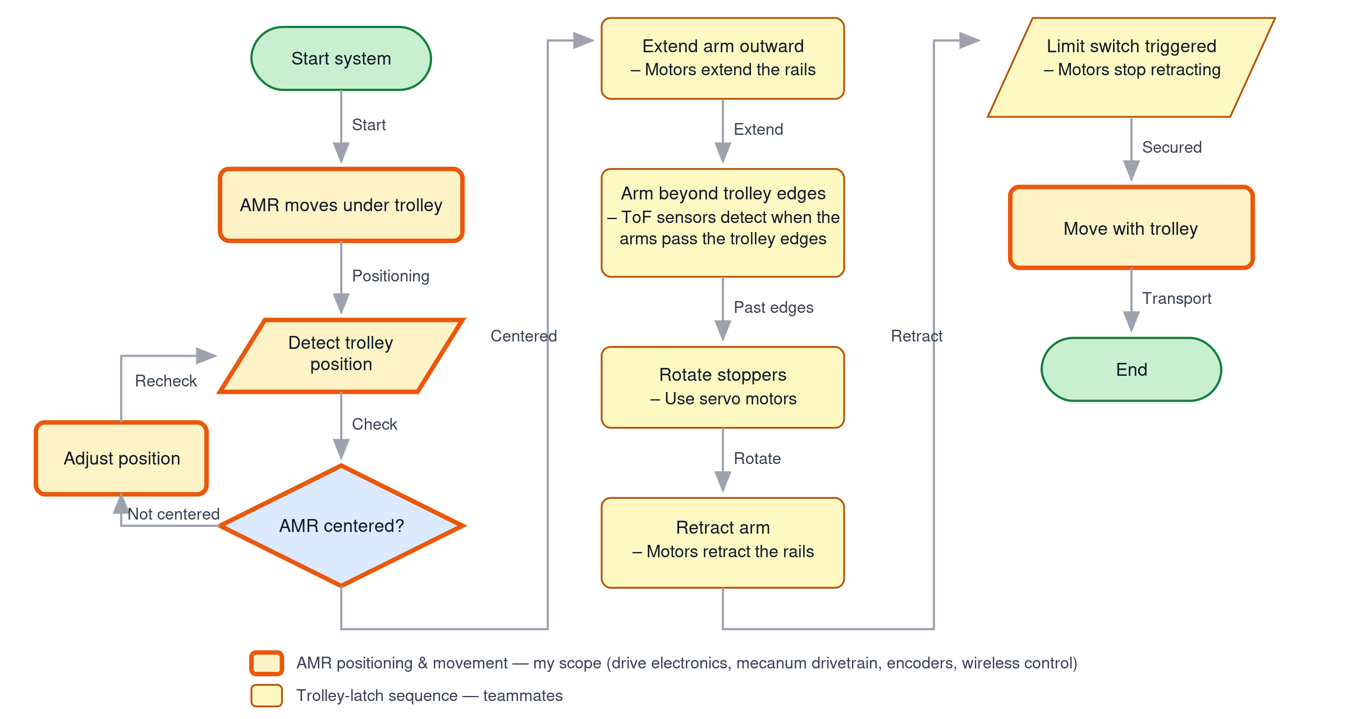
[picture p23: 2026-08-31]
team_flowchart.png

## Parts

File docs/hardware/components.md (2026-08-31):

# Component list

What is on the robot, what each part is doing there, and what it is worth
keeping if the robot is broken up for parts.

Rows marked **⬚ TO FILL** are things that exist physically but whose
specifications were never written down. They are listed rather than omitted so
nobody mistakes a gap for a completed survey.

---

## 1. Power

| Qty | Part | Spec | Notes |
|---|---|---|---|
| 1 | Battery pack | **36 V, 10 Ah Li-Ion, 2–3 C (20–30 A)** | Sized in the term paper: 240 W average draw, 22.8 A peak at 36 V. **Custom-built — no cell/BMS datasheet exists**, and the BMS is what latches off on buck inrush (`startup.md` §3) |
| 1 | Main switch | **40 A** | Feeds all three bucks |
| 1 | Buck converter | 36/48 V in → **24 V, 30 A** (720 W) | wheel motors |
| 1 | Buck converter | 24/36/48 V in → **12 V, 25 A** (300 W) | arm extension, behind the button |
| 1 | Buck converter | 36/48/60 V in → **5 V, 20 A** (100 W) | servos + BTS7960 logic |
| 1 | Latching mushroom button | **1NO 1NC DPST**, AC 660 V 10 A, latching self-lock | Gates the **red (positive) conductor of the 12 V buck's input**. **Wired as an ENABLE, not an E-stop** — read `startup.md` §1 |
| 1 | Fuse | 10 A *(claimed in `hardware-architecture.md` §6)* | ⬚ TO FILL: rating confirmation and physical location |
| — | Pack charger | ⬚ TO FILL | Must match a pack whose cell count and BMS are undocumented |
| — | ESP power | USB **power bank** | Both ESP32-S3 boards. Independent of the pack entirely |

> **The mushroom button is rated for AC, and is switching DC.** AC 660 V 10 A is
> an alternating-current rating, where the current crosses zero 100 times a second
> and any arc self-extinguishes. A 36 V DC arc does not, so the DC breaking
> capacity of these contacts is materially lower than the printed figure. It is
> switching the 12 V buck's input — under 10 A even at the buck's full 300 W
> output, and far less at normal arm loads — so this is a note about margin, not
> a fault. **[The AC rating is printed on the part; no DC rating is quoted.]**

> **The battery is the least documented part of the robot.** It was custom-built,
> so there is no cell chemistry, no BMS part number, no continuous or peak
> discharge rating, and no charge profile written down anywhere. Everything the
> robot does electrically is bounded by a component whose limits cannot be looked
> up. Opening the pack and recording the cells and BMS is the only way to
> establish them.

**Rail loads:**

| Rail | Feeds |
|---|---|
| 24 V | 4× BLD-120A wheel driver |
| 12 V | arm-extension wormgear motors, via the BTS7960 B+/B− terminals |
| 5 V | Arm PCB J3 → 4× flipper servo + both BTS7960 logic supplies |
| USB | both ESP32-S3 boards — **not fed from the pack** |

---

## 2. Drivetrain

| Qty | Part | Spec | Notes |
|---|---|---|---|
| 4 | **BLD-120A** BLDC driver | 12–30 V in; **8 A continuous, 30 A instantaneous (<3 s)** | Native PWM speed input. No ALM output — "RUN/ALM" is an LED only |
| 4 | BLDC gearmotor | **80 mm flange, DC 24 V, 3000 RPM, 15:1** | Full table below |
| 4 | Mecanum wheel | **152 mm** diameter | r = 0.076 m |
| 4 | Custom motor mount | machined, already fitted | Diametric magnets already bonded to the shafts (for the abandoned encoders) |
| 1 | Chassis | **800 × 500 mm**, 2020 aluminium extrusion | 80 mm suspended sub-frame shelf below the main frame for the battery. Supports 15–20 kg distributed, ~70 kg with a single cross brace |

### Motor — 80 mm flange series

Datasheet: [`img/motor-80-flange-spec-table.jpeg`](img/motor-80-flange-spec-table.jpeg):

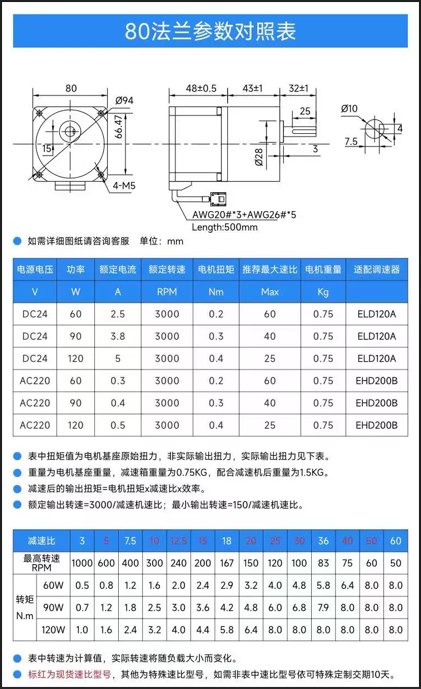
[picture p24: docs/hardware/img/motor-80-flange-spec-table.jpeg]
80 mm flange motor datasheet spec table


| | |
|---|---|
| Flange | 80 × 80 mm, 4× M5 |
| Supply | **DC 24 V** — matches the 24 V rail |
| Rated speed | **3000 RPM** at the motor |
| Gearbox | **15:1** (a stocked ratio) — see the caveat below |
| Output shaft | Ø10 mm, ~25 mm usable |
| Weight | 0.75 kg motor, **1.5 kg with gearbox** → ~6 kg of gearmotor on the robot |
| Cable | **AWG20 × 3 + AWG26 × 5**, 500 mm |

> ⚠️ **Confirm the gearbox ratio off its own label if anything depends on it.**
> The purchase listing groups this motor as *"80 flange, 120 W, 24 V, ratio
> 10–18"*, so the ratio is a purchase option within a band rather than a fixed
> property of the part number. Everything in this project has been documented as
> **15:1**, and the speed ceiling below is computed from it — but the ceiling
> moves a long way across that band: 10:1 gives 2388 mm/s, 15:1 gives 1592 mm/s,
> 18:1 gives 1326 mm/s. At 18:1 the ceiling would fall *below* one of the existing
> `max_lin_mm_s` estimates. **[The 15:1 figure is inherited from earlier project
> notes, not read off the gearbox.]**

### The variant fitted is **120 W** **[VERIFIED — Bryan, 2026-08-16]**

| | 60 W | 90 W | **120 W ← fitted** |
|---|---|---|---|
| Rated current | 2.5 A | 3.8 A | **5 A** |
| Base torque | 0.2 N·m | 0.3 N·m | **0.4 N·m** |
| Output torque at 15:1 | 2.4 N·m | 3.6 N·m | **4.8 N·m** |
| Datasheet max ratio | 50 | 40 | **25** — 15:1 is within it |

**This sets P-sv: 120 W**, which is the **top of the trim's 30–120 W range**. See
`startup.md` §6.

### What 120 W × 4 means for the rest of the machine

| | |
|---|---|
| Tractive force per wheel (torque-limited) | 4.8 N·m ÷ 0.076 m = **63 N** |
| All four wheels | **253 N** |
| Current at rated load | 5 A × 4 = **20 A at 24 V = 480 W** |
| Same, drawn from the 36 V pack | ~13.3 A ideal, **~15.7 A at 85 % buck efficiency** |
| Driver headroom | 8 A each = 32 A at 24 V, well above the motors' 20 A |
| Pack endurance at full drivetrain load | 360 Wh × 0.85 ÷ 480 W ≈ **38 min**, and less in practice — a pack is not discharged to empty |

Two things worth drawing out of that table:

- **The 24 V buck is rated 30 A** against a ~20 A four-wheel demand — about 50 %
  headroom, so the drivetrain rail is adequately sized. The pack sees ~16 A
  through it.
- **253 N of tractive force is more than the tyres can use.** Traction, not
  torque, is the binding constraint: once the wheels slip, more motor buys
  nothing, and the ceiling is µ · robot weight.

> ### How this project answered the traction constraint **[VERIFIED — term paper Table 1]**
>
> **Not by lifting. By making the robot heavy.** The requirements table specifies:
>
> | Requirement | Target | Reasoning |
> |---|---|---|
> | AMR total mass | **≥ 25 kg** | *"Drive wheels maintain grip without slipping under load"* |
> | Able to move | **100 kg** | trolley + load |
>
> The mass requirement **is** the mitigation, chosen deliberately over a lifting
> clamp. `docs/pdr-falali-amr.pdf` lists *"uses the trolley's own caster wheels and
> the AMR never lifts the trolley"* under **Innovation In Our Project** — no-lift
> is a design position, not a shortfall.
>
> **As delivered:** ~30 kg, against a ≥25 kg requirement. The clamp grips
> horizontally and transfers no weight.
>
> | Result | Evidence |
> |---|---|
> | **100 kg drive test — passed** | the acceptance test. `docs/pdr-falali-amr.pdf`, and `docs/media/videos/load-test-100kg.mp4` |
> | **~150 kg moved — requirement exceeded by ~1.5×** | three adults on a trolley platform, dry concrete. **[OBSERVED — Bryan; mass estimated, not weighed]** |
>
> **The numbers, at 30 kg on dry concrete** (µ_eff ≈ 0.5 after the mecanum
> geometric penalty):
>
> | | Force |
> |---|---|
> | Available traction | **147 N** (123 N at the 25 kg minimum) |
> | Aligned breakaway, **100 kg** (requirement) | 60–75 N → **~2× margin** |
> | Aligned breakaway, **~150 kg** (observed) | 90–113 N → **1.3–1.6× margin** |
> | Misaligned-castor startup, 100 kg | 75–130 N |
> | The team's own worst-case castor figure (µ 0.15 × 100 kg) | **147 N** |
>
> Comfortable at the requirement, still positive at the ~150 kg actually moved,
> and level with the team's own worst-case misalignment number — which is
> presumably why *"moves under all 4 castor orientations"* was written as a
> separate acceptance criterion rather than assumed. It passed.
>
> **Floor is the variable.** Concrete is the best case; painted ≈ 103 N and wet
> ≈ 88 N at 30 kg, both of which fall into or below the misaligned band. The
> 200 kg figure modelled in the caster report is **not** a project requirement —
> see [`../research/2026-07-13-caster-load-mechanics.md`](../research/2026-07-13-caster-load-mechanics.md),
> which was built on inputs that contradict Table 1.

> The motor datasheet lists **ELD120A** as the matching controller for the DC 24 V
> variants. **The robot does not use one — there is no ELD anywhere on this
> machine, only BLD-120A.** The driver was bought separately and is sold for
> exactly this duty ("12V 24V, within 120 W, 42/57/60 frame, with hall
> controller"). The ELD reference in the motor datasheet is simply a different
> product. **[VERIFIED — Bryan, 2026-08-17]**

### The 5 wires nobody is using

`AWG20 × 3 + AWG26 × 5` is three phase wires and **five hall-sensor wires**
(V+, GND, HA, HB, HC). **The motors have hall sensors. They always did.**

The BLD-120A simply does not bring them out — it has no FG or tacho terminal,
which is why `gotchas.md` §13 says there is no wheel-speed feedback. But the
signal exists inside the motor cable.

As a route back to wheel-speed feedback it is considerably less involved than
the AS5600 encoders, which failed for two independent board-level reasons
(`boards.md` §1). One hall line per motor into a spare GPIO would give 3 pulses
per motor revolution = 45 per wheel revolution at 15:1 — enough resolution for
stall detection and speed estimation. **[HYPOTHESIS — the wire count
and colours are from the datasheet; nobody has put a scope on them.]**
*Experiment: with 24 V applied and a wheel turned by hand, scope any AWG26 line
against motor ground. A 3-per-rev square wave confirms it.*

### Speed ceiling — an independent check on `max_lin_mm_s`

The gearing fixes the top speed, and this is the first hard number the project
has had for it:

```
3000 RPM ÷ 15         = 200 RPM at the wheel
π × 152 mm            = 477.5 mm circumference
200 / 60 × 477.5      = 1592 mm/s          ← hard geometric ceiling
```

`gotchas.md` Open Issue B lists four estimates of `max_lin_mm_s` spanning
1155–1657 mm/s. Against a 1592 mm/s ceiling:

| Estimate | % of ceiling | |
|---|---|---|
| 1155 | 73 % | plausible |
| **1231** *(in `config.h`)* | **77 %** | plausible |
| 1384 | 87 % | plausible, optimistic |
| 1657 | **104 %** | **impossible — rejected** |

**[VERIFIED — datasheet arithmetic]** This does not prove 1231 is right, but it
removes the top of the range and shows the configured value is sensibly below a
real physical limit.

The datasheet also gives a **minimum** output speed of 150 RPM ÷ 15 = 10 RPM =
**80 mm/s**. Measured break-away is ~413 mm/s — **five times higher than the
drivetrain's stated minimum.** That points the "minimum speed" open item in
`hardware-architecture.md` §9 at **friction and load**, not at gearing, wheel
diameter or the driver's control range. **[HYPOTHESIS — arithmetic is solid, the
friction explanation is inferred.]**

### BLD-120A driver detail

**[VERIFIED — `BLDC-BLD120A-bldc-motor-controller-specs.pdf`, read 2026-08-16]**

| | |
|---|---|
| Supply | 12 / **24** / 30 V DC (min / typ / max) |
| Output current | **8 A** rated, 30 A instantaneous (< 3 s) |
| Size | 96 × 60 × 24.5 mm |
| Terminals | `BRK EN F/R COM SV` · `REF+ HU HV HW REF−` · `W V U` · `DC+ DC−` |
| Trims | **RV**, **P-sv**, **ACC/DEC** — three, not two. `startup.md` §6 |
| Indicator | Green = power good, red = fault. **One LED, not an output** |

**Three settings per driver** — see `startup.md` §6. **RV** fully anticlockwise
or external speed control fails; **P-sv** to 5 A / 120 W; **ACC/DEC** to minimum.

#### The PWM frequency question is settled: **1–3 kHz**

The two older manuals disagreed — `BLD-120-English-version.pdf` says 1–10 kHz,
`SYS-BLD-120A-manual.pdf` says 1–3 kHz. **The BLD-120A-specific spec sheet
agrees with the SYS manual:** *"The pulse frequency range: 1-3KHz."*

The firmware's **2 kHz** (`pins::kSvPwmFreqHz`) is correct. The 5 kHz value that
`hardware-architecture.md` §3 used to carry was **outside spec**, and the 20 kHz
before it was well outside.

**Duty range matters too:** the datasheet advises **2 %–90 %**, where 2 % duty =
5 % of top speed and **90 % duty = maximum**. Commanding 100 % is outside the
advised range and buys nothing.

#### There is definitively no speed or alarm output

The English manual's feature list advertises *"Speed signal output"* and
*"Abnormal alarm signal output."* **Both are boilerplate that does not match this
driver.** The Driver Control Terminal table in that same document lists exactly
five pins — `SV COM F/R EN BRK` — and the spec sheet's full port table adds only
hall, motor and power terminals. There is no FG pin and no ALM pin anywhere.
"RUN/ALM" is an LED.

This confirms what was bench-established on 2026-07-27 and is recorded in
`pins.h` (`kWheelALARM == kNoPin`). **The feature bullet is the thing that is
wrong, not the project's conclusion** — worth knowing, because that bullet is
exactly the kind of thing that sends someone hunting for a terminal that does not
exist.

#### The hall signals are on the driver's own screw terminals

`REF+ HU HV HW REF−`. This makes the speed-feedback idea in §2 above much easier
than it first looked: **no cable splicing** — the hall lines land on accessible
screw terminals on each driver.

⚠️ They are **5 V** logic (`REF+` is the hall supply positive). The ESP32-S3 is
not 5 V tolerant, so a divider or level shifter is mandatory.

#### ⚠️ Our 3.3 V SV drive may be costing ~30 % of top speed **[HYPOTHESIS]**

The datasheet's analog curve runs **0.25 V → 5 % speed** and **4.7 V → maximum**,
and PWM mode is documented as *"Add 5V between SV and GND."* SV is driven here
straight from a GPIO through R7 (1.5 kΩ) with **no level shifting**, so it swings
to about **3.3 V, not 5 V**.

Two competing models, with materially different predictions:

| Model | Top speed |
|---|---|
| Driver reads **duty** (as the PWM section implies) | 90 % duty → 3000 RPM → **1592 mm/s** |
| Driver reads **average voltage** (as the analog curve implies) | 3.3 V → ~2100 RPM → **~1100 mm/s** |

The measured `max_lin_mm_s` estimates were 1155, 1231, 1384 and 1657 mm/s. **The
cluster at the low end sits suspiciously close to the amplitude-limited
prediction.**

*Experiment that settles it:* level-shift SV to a 5 V PWM on one wheel — a single
transistor stage or a 74AHCT-type buffer — and re-measure top speed. If it rises
toward 1592 mm/s, every wheel has been running at roughly 70 % of its capability
all along, and `max_lin_mm_s` has been calibrating a limitation rather than a
property of the machine.

---

## 3. Signal conditioning — Driver PCB ×4

Per board (multiply by 4):

| Qty | Ref | Part | Notes |
|---|---|---|---|
| 3 | Q1–Q3 | **2N3904** NPN, TO-92 | **EBC pinout.** A BC547 is CBE and must be rotated 180° — `boards.md` §2 |
| 3 | R1–R3 | 10 kΩ, axial THT | base series |
| 3 | R4–R6 | 100 kΩ, axial THT | base pulldown — do not omit |
| 1 | R7 | 1.5 kΩ, axial THT | SV series |
| 2 | J1, J2 | 1×05 male header 2.54 mm | J1 = ESP side, J2 = driver side |
| 4 | H1–H4 | M3 mounting | |

**Totals for four boards:** 12× 2N3904, 12× 10 kΩ, 12× 100 kΩ, 4× 1.5 kΩ,
8× 1×05 header.

---

## 4. Sensors

| Qty | Part | Address | Where | Notes |
|---|---|---|---|---|
| 4 | **VL53L0X** ToF | `0x29` → re-addressed | base corners FL/FR/RL/RR | **Breakout must expose XSHUT** |
| 4 | **VL53L0X** ToF | → `0x30`–`0x33` | arm X1/X2/Y1/Y2 | same requirement |
| 1 | **BNO085** IMU | `0x4A` | base, J19 | ⚠️ verify module pin order before seating — `boards.md` §1 |
| 1 | **ADS1115** 16-bit ADC | **`0x48`** (fixed in copper) | base, J8 | 4-channel, reads the current sensors |
| 4 | **ACS758LCB-050B** current sensor | analog | inline on motor-supply **negative**; **signal not connected** | See the warning below |
| 8 | Limit switch | — | arm, SW1–SW8 | switch-to-ground, firmware pulls up |

> ## ⚠️ The current sensors are installed but not wired up
>
> **[OBSERVED — Bryan, 2026-08-16]** The four ACS758 are physically inline with
> the **negative side of the motor driver supply**, but their outputs are **not
> connected to J9/J12/J14/J17.** Right now they are conducting current and
> reporting to nobody.
>
> **This means the base has no drivetrain fault signal at all.** The chain in
> `boards.md` and `pins.h` reads: no ALM terminal → no encoders → current sense is
> the *only* thing left. That last link is currently open. `StallDetector` runs on
> an ADS1115 that sees nothing, and `gotchas.md` Open Issue C — "`kWheelStallAmps`
> has never been calibrated under load" — is understated: it has never been
> *connected*.
>
> **Wiring them up is four wires**, one per sensor, from the sensor's `VIOUT` pin
> to pin 4 of its connector. Power and ground are already on pins 1 and 2 of those
> headers. Low-side sensing is fine here — the ACS758's current path is galvanically
> isolated from its signal side, so sitting on the motor negative does not upset the
> 3.3 V referencing.
>
> Get the corner mapping right when you do: **J9=FL=A0, J12=FR=A1, J14=RL=A2,
> J17=RR=A3** (`boards.md` §1). Then calibrate `kWheelStallAmps` under a real
> loaded trolley — the present value of 10 A came from wheels off the ground.

**Why the ACS758 and not the more sensitive ACS712:** the driver is rated 8 A
continuous / 30 A instantaneous, and an ACS712-05B **clips at 5 A** — it cannot
tell 5 A from 30 A, which is precisely the difference between "working hard" and
"something is badly wrong." The resolution penalty is only ~1.5×, not the ~25× a
sensitivity comparison implies, because Hall noise scales with sensitivity. Full
reasoning in `hardware-architecture.md` §6.

**Prefer the `-050B` (bidirectional) over `-050U`:** applying BRK can push energy
back toward the supply. `B` costs one bit of range and removes the question.

### Removed / obsolete

| Part | Status |
|---|---|
| 4× **AS5600** magnetic encoder | **Abandoned 2026-08-13.** Two board-level faults made them unworkable — `boards.md` §1. **The sensor boards and shaft magnets are still physically mounted on the motors**, but are not wired to anything and appear nowhere in the firmware |
| 1–2× **TCA9548A** I²C mux | No longer needed. Address `0x70` survives in `pins.h` only so the bring-up scan can report whether it is present |
| PCA9548-type mux (external) | Overheated and failed with >2 AS5600 attached. Not part of the handover **[OBSERVED — Bryan]** |

> **There is no wheel-speed feedback of any kind.** Per-wheel current is the only
> drivetrain fault signal, and `cfg::kWheelStallAmps` has never been calibrated
> under load (`gotchas.md` Open Issue C).

---

## 5. Arm subsystem

| Qty | Part | Spec | Notes |
|---|---|---|---|
| 2 | **BTS7960** H-bridge module | 43 A | X and Y extension. 12 V to its own B+/B− terminals |
| 2 | DC wormgear motor | 12/24 V, **250 kg·cm** (≈24.5 N·m), **self-locking** | arm extension, run at 12 V, driven by the BTS7960s |
| 4 | **GX3345BLS** servo | **45 kg·cm** | flippers. 5 V rail. Driven 170° home → 80° flipped, 500–2500 µs at 50 Hz. *(The `BLS` suffix conventionally denotes a brushless servo — unconfirmed, and it matters for stall-current sizing)* |
| 1 | **PCA9685** 16-ch PWM driver | `0x40` | Plugged into one of the Arm PCB's **ToF headers** for I²C. `boards.md` §3 |

> **What the PCA9685 actually drives.** It drives the **four flipper servos**,
> not the wormgear motors. `arm/src/MotorController.cpp` calls `pwm_.setPWM()`
> only from `setServoPulse()`, on channels 0–3
> (`Y_SERVO_1`, `Y_SERVO_2`, `X_SERVO_1`, `X_SERVO_2`). The wormgear motors go
> through the two **BTS7960** modules on direct GPIO — J1 and J2 on the arm board.
> **[VERIFIED — source]** Worth stating plainly because it is easy to misremember
> the other way round.

> ⚠️ **Servo stall current versus the 5 V buck.** Four 45 kg·cm digital servos can
> pull several amps each when stalled or moving under load, and all four flip
> together. They share the 5 V rail with both BTS7960 logic supplies. The buck's
> rail is rated **20 A**, which is generous for four servos even at stall, so
> capacity is unlikely to be the constraint. **[Rating VERIFIED; margin not
> measured.]**
>
> The remaining question about this rail is its **input** range, not its output:
> the module is sold as a 36/48/60 V converter. A 36 V pack is *nominally* at the
> bottom of that range and sags lower under load and toward end of charge. If the
> module's true minimum input is 36 V rather than something below it, the 5 V rail
> could drop out late in a discharge — which would kill servos mid-flip and look
> like a firmware fault. **[HYPOTHESIS — the listing quotes nominal input
> voltages, not the hard minimum.]** *Check: read the module's own label for its
> input range, or meter the 5 V output with the pack drawn down.*

---

## 6. Controllers

| Qty | Part | Notes |
|---|---|---|
| 2 | **ESP32-S3-DevKitC-1 N16R8** | 16 MB flash, 8 MB octal PSRAM. One base, one arm |
| 1 | **Xbox BLE gamepad** | The S3 is BLE-only, so Switch pads cannot pair. Bluepad32 |

**MAC addresses** (ESP-NOW, WiFi channel 1, plain text, NUL-terminated):

| | |
|---|---|
| Base | `14:C1:9F:3B:7B:E4` |
| Arm | `3C:DC:75:5C:8B:08` |

> `ARM_ESP_MAC` in `arm/src/HardwareConfig.h` is **decorative** — it is printed at
> boot as a label and never applied with `esp_wifi_set_mac()`. A wrong peer MAC
> gives perfect silence with nothing on screen looking wrong. `gotchas.md` §5.

---

## 7. Board-mounted passives and connectors — Wheel Drive PCB

From the KiCad footprints:

| Qty | Part | Refs |
|---|---|---|
| 4 | 1×03 male header, 2.54 mm | J2, J10, J13, J16 |
| 8 | 1×04 male header | J1, J9, J11, J12, J14, J15, J17, J18 |
| 4 | 1×05 male header | J4–J7 |
| 4 | 1×06 male header | TOF5–TOF8 |
| 2 | 1×10 male header | J8, J19 |
| 2 | **1×22 female** header | U6 — **socket it, do not solder the DevKit down** |
| 1 | Phoenix MKDS-1,5-2-5.08 terminal block, 2-pos | J3 |
| 4 | M3 screw + standoff | H1–H4 |

≈108 male positions (three 40-pin breakaway strips) and 44 female (two strips).

**Arm Subsystem PCB** takes the same 1×22 female pair for U1, 2× 1×06 (J1, J2),
4× 1×03 (S1–S4), 8× 1×02 (SW1–SW8), 4× 1×06 (TOF1–TOF4), and one MKDS terminal
block (J3).

---

## 8. If the robot is being broken up for parts

The audience note for these docs mentions members scavenging Falali to feed
other projects. This is a condition report, not a recommendation — what state
each part is in, and what carries over with it.

**Unmodified and known-good:**

- **2× ESP32-S3-DevKitC-1 N16R8.** 16 MB/8 MB parts, socketed, nothing soldered
  to them.
- **4× BLD-120A + BLDC motor + 15:1 gearbox + 152 mm mecanum wheel.** The most
  expensive subsystem. **P-sv is trimmed per motor**, so a driver separated from
  its motor loses that setting.
- **2× BTS7960**, unmodified.
- **BNO085, ADS1115, PCA9685.** Standard breakouts.

**Carries a caveat:**

- **8× VL53L0X.** Only the variants that break out XSHUT work in this design; a
  module pulled from here without XSHUT cannot come back.
- **4× ACS758LCB.** Ratiometric and currently fed from a 3.3 V rail. At 5 V they
  need a divider into whatever ADC reads them.
- **Battery + BMS + bucks.** The pack's inrush behaviour (`startup.md` §3) and
  its undocumented internals (§1) travel with it.

**Known-suspect or already failed:**

- **4× AS5600 breakouts.** Two of the four measured 60 kΩ and 165 kΩ against
  280 kΩ for the healthy pair. Untested since.
- **The external PCA9548-type mux.** Failed thermally with more than two AS5600
  attached.
- **Driver PCBs.** Trivial parts cost; the value is the design in
  `KiCad/Driver PCB/` rather than the assembled board.

**Not reproducible from this repo:** the four **custom motor mounts** are
machined for this chassis, and nothing here records their geometry. Once
separated from the robot there is no drawing to make more from.

---

## Gaps

Everything marked **⬚ TO FILL** above, consolidated:

**Still open:**

- [ ] The **5 V buck's true minimum input voltage** (§5). Its listing quotes
      36/48/60 V; a 36 V pack sags below 36 V under load and toward end of charge.
- [ ] Battery: cell chemistry/count, BMS continuous and peak rating, charge
      profile, connector. **Custom-built, nothing documented**
- [ ] Fuse: rating and physical location
- [ ] The **gearbox ratio**, confirmed off the gearbox label rather than
      inherited from project notes (§2). The speed ceiling depends on it.
- [ ] Chassis dimensions and the mecanum wheel layout (which way each roller set
      faces) — nothing in the repo records this, and it cannot be inferred

**Closed 2026-08-17:**

- [x] Buck converters: **24 V/30 A, 12 V/25 A, 5 V/20 A** — §1. The 24 V rail has
      ~50 % headroom over the drivetrain's 20 A, and the 5 V rail is generous for
      the servos
- [x] Mushroom button: **1NO 1NC DPST, AC 660 V 10 A**, latching — §1. The unused
      **NC contact is physically present**
- [x] It gates the **12 V buck's input**, so the inrush staggering works as
      intended — `startup.md` §2 and §3
- [x] Arm wormgear motors: **250 kg·cm, self-locking**, 12/24 V — §5
- [x] ESPs run from a **USB power bank** — §1
- [x] There is **no ELD120A** on this machine, only BLD-120A — §2

**Closed 2026-08-16:**

- [x] Motor: 80 mm flange, DC 24 V, 3000 RPM, 15:1, Ø10 shaft, **120 W / 5 A /
      4.8 N·m at the output** — §2
- [x] **P-sv setting: 5 A ≡ 120 W at 24 V** — `startup.md` §6
- [x] PWM frequency conflict resolved: **1–3 kHz**, so the firmware's 2 kHz is
      correct — §2
- [x] No FG or ALM terminal exists — re-confirmed against the full port table,
      and the contradicting feature bullet identified as boilerplate — §2
- [x] Flipper servos: **GX3345BLS**, 45 kg·cm — §5
- [x] Main switch: **40 A** — §1
- [x] ACS758 fitted status: **installed inline on motor-supply negative, signal
      not connected** — §4
- [x] PCA9685 exists and is plugged into a ToF header — §5, `boards.md` §3
- [x] Motors have **hall sensors** on 5 unused AWG26 wires — §2
- [x] Top speed ceiling **1592 mm/s** (152 mm wheels), which rejects the
      1657 mm/s estimate of `max_lin_mm_s` — §2
- [x] Chassis **800 × 500 mm** 2020 extrusion; battery **36 V 10 Ah Li-Ion,
      2–3 C** — §1, from the term paper
- [x] Traction answered by the **≥ 25 kg mass requirement**, not by lifting;
      100 kg drive test passed and ~150 kg observed — §2

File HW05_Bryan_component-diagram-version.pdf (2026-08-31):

## TrolleyBot — Trolley-Latching Autonomous Mobile Robot

Homework 05 · Functional diagram & individual contributions

### Bryan

8 August 2026

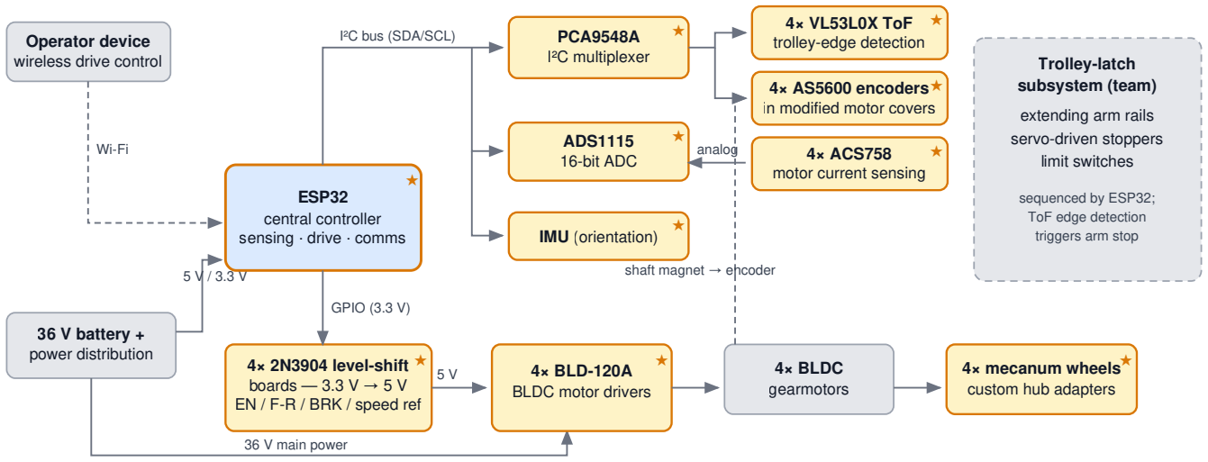
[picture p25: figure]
Operator device wireless drive control; 36 V battery + power distribution; 36 V main power; ESP32 central controller sensing · drive · comms; I²C bus (SDA/SCL); PCA9548A I²C multiplexer; 4× VL53L0X ToF trolley-edge detection; 4× AS5600 encoders in modified motor covers; ADS1115 16-bit ADC; analog; 4× ACS758 motor current sensing; IMU (orientation); 4× 2N3904 level-shift boards — 3.3 V → 5 V EN / F-R / BRK / speed ref; GPIO (3.3 V); 4× BLD-120A BLDC motor drivers; 4× BLDC gearmotors; shaft magnet → encoder; 4× mecanum wheels custom hub adapters; Trolley-latch subsystem (team)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

MY CONTRIBUTIONS

Planned & assembled the base electrical system (19 components). Architected the full sensing/drive circuit around a single ESP32: 4× VL53L0X ToF rangefinders and 4× AS5600 encoders behind a PCA9548A I²C multiplexer (resolves fixed-address clashes on the shared bus), 4× ACS758 current sensors digitised by an ADS1115 ADC on the same I²C bus, an IMU, and 4× BLD-120A BLDC drivers.
Designed the 3.3 V→5 V motor-driver interface. ESP32 logic levels were not reliably registered by the BLD-120A's 5 V control inputs — the hardest debugging problem of the build. Solved it with a 2N3904 interface board per driver: each GPIO drives an NPN via a 10 kΩ base resistor (100 kΩ pull-down for a defined off-state), and the transistor sinks the driver's internally pulled-up control line (EN, F/R, BRK) to COM; 1.5 kΩ sets the speed reference. Schematic and PCB drawn in KiCad.
Wired and soldered most of the sensor harnesses and connections across the base circuit.
Designed & fabricated a modified motor cover housing each AS5600 encoder PCB, with the diametric magnet aligned on the motor shaft axis. Designed & fabricated wheel-hub adapters and motor mounts coupling the mecanum wheels to the gearmotor shafts, plus the ToF sensor mounts. Ran the integration drive test: drove the fully constructed base untethered on 36 V battery power under ESP32 wireless control.

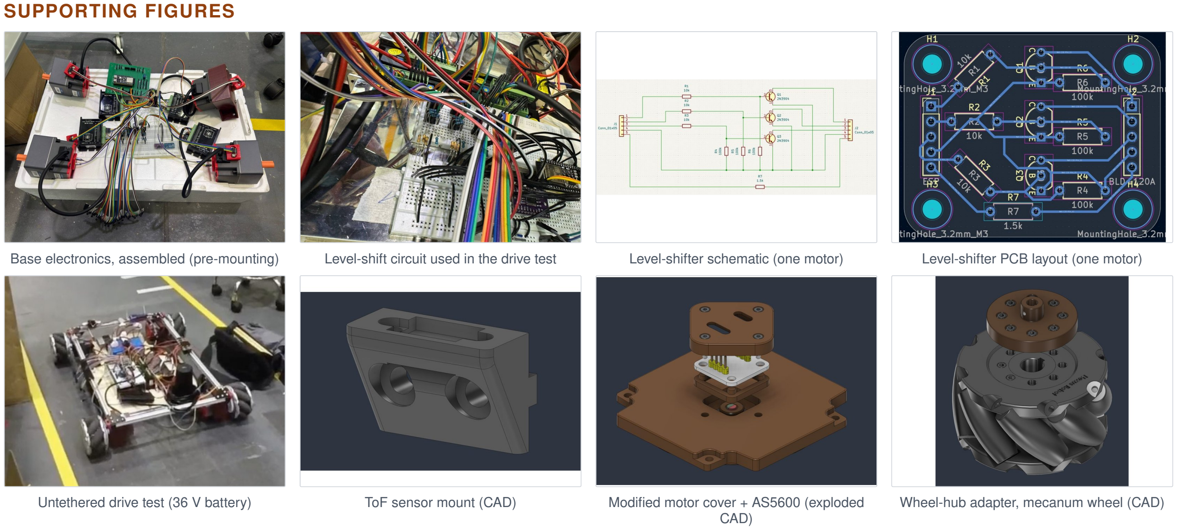
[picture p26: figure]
SUPPORTING FIGURES; CAD); Wheel-hub adapter, mecanum wheel (CAD)

Base electronics, assembled (pre-mounting) | Level-shift circuit used in the drive test | Level-shifter schematic (one motor) | Level-shifter PCB layout (one motor)
Untethered drive test (36 V battery) | ToF sensor mount (CAD) | Modified motor cover + AS5600 (exploded
★ orange outline = my contribution (planning · design · fabrication · assembly · test) | grey = teammates / off-the-shelf

1.

2.

3.

4.

5.

6.

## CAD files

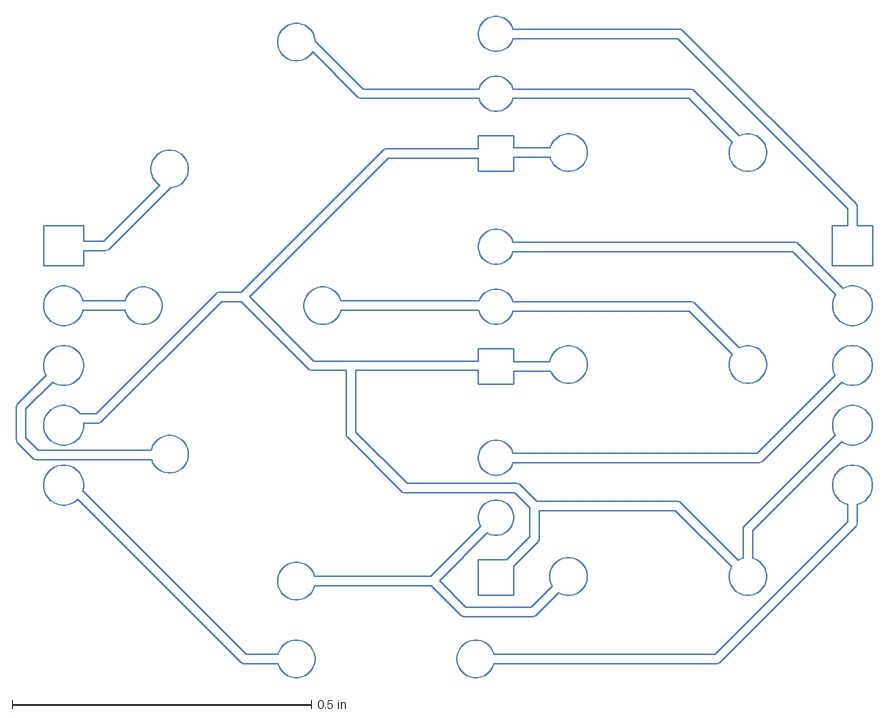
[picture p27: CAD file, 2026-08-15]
KiCad/Driver PCB/Driver PCB-B_Cu.dxf
1.43 x 1.11 in

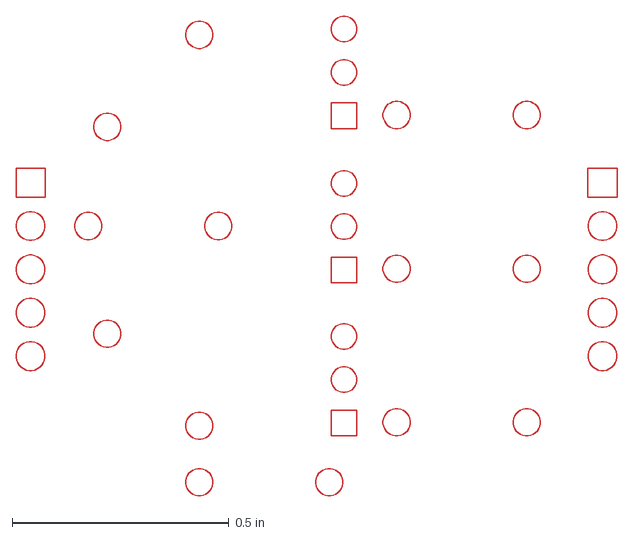
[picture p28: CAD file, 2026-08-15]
KiCad/Driver PCB/Driver PCB-F_Cu.dxf
1.39 x 1.11 in

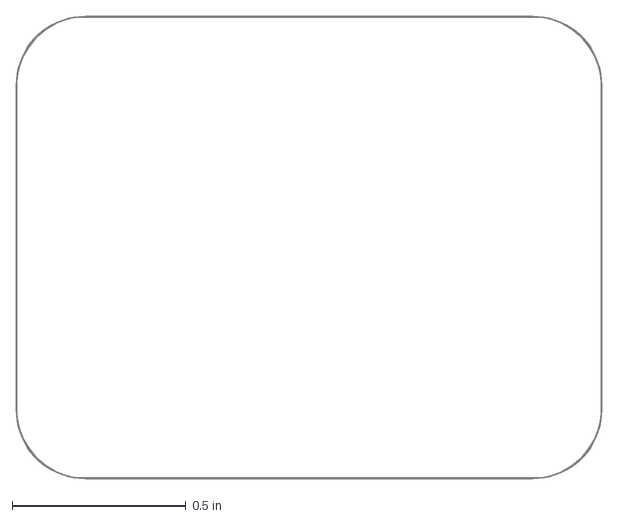
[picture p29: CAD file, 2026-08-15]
KiCad/Driver PCB/Driver PCB-Edge_Cuts.dxf
1.69 x 1.33 in

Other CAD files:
KiCad/Driver PCB/Driver PCB-B_Mask.dxf
KiCad/Driver PCB/Driver PCB-B_Paste.dxf
KiCad/Driver PCB/Driver PCB-B_Silkscreen.dxf
KiCad/Driver PCB/Driver PCB-F_Mask.dxf
KiCad/Driver PCB/Driver PCB-F_Paste.dxf
KiCad/Driver PCB/Driver PCB-F_Silkscreen.dxf

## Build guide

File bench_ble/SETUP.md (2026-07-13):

# bench_ble — Bluepad32 gamepad build

Separate PlatformIO project (ESP-IDF + Arduino-as-component) for driving the bench rig
with an Xbox BLE controller. It exists apart from the root Arduino project because
Bluepad32 replaces the Bluetooth stack with BTstack and ships its own framework build.

Generated from: https://github.com/ricardoquesada/esp-idf-arduino-bluepad32-template
(pioarduino platform, ESP-IDF v5.4.2). Bluepad32 for Arduino v4.2.0.

## Vendored components (git-ignored)

`components/` (arduino, bluepad32, bluepad32_arduino, btstack, cmd_*) and all build
artifacts are git-ignored to keep the repo lean. Re-fetch them on a fresh checkout with:

    git clone --recursive https://github.com/ricardoquesada/esp-idf-arduino-bluepad32-template _tpl
    rsync -a _tpl/components/ components/ && rm -rf _tpl

(The component URLs are recorded in `.gitmodules`.)

## Build / flash / monitor

    pio run  -d bench_ble -e esp32-s3-devkitc-1            # build
    pio run  -d bench_ble -e esp32-s3-devkitc-1 -t upload  # flash (native USB / usbmodem*)
    python teleop.py                                        # monitor (glob finds usbmodem*)

## Pairing an Xbox controller

Xbox Wireless **model 1914** (Series X/S), firmware >= v5.15, BLE-only. Turn it on, then
hold the **Pair** button ~3 s until it flashes fast. Bluepad32 auto-connects; you should see
`CALLBACK: Controller is connected` + `Controller model: Xbox Wireless Controller`.

## Task 4 note: Console vs Serial

The stock sketch prints via Bluepad32's `Console` (default `CONFIG_BLUEPAD32_USB_CONSOLE_ENABLE=y`),
which is incompatible with Arduino `Serial`. Our shared core (`../src/bench_core.h`) prints via
`Serial`, so when wiring it in (Task 4) set `CONFIG_BLUEPAD32_USB_CONSOLE_ENABLE=n` in
`sdkconfig.defaults`, and add `-I ${PROJECT_DIR}/../src` + the Pololu VL53L0X component.

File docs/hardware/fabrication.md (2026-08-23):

# Re-ordering, modifying and repairing the boards

Written for someone who can solder but has never opened KiCad.

---

## 1. What all these files are

A KiCad project is two drawings plus a pile of machine-readable exports.

| File | What it is | Do you need it? |
|---|---|---|
| `*.kicad_sch` | **Schematic** — what is connected to what. No physical positions | To understand the circuit |
| `*.kicad_pcb` | **Layout** — where the copper physically goes | To change the board |
| `*.net` | **Netlist** — a plain-text dump of every connection. This is what `boards.md` was built from | To check something without opening KiCad |
| `*.kicad_pro` / `.kicad_prl` | Project settings / local UI state | Ignore |
| `*.gbr`, `*.gbl`, `*.gtl`, `*.gto`… | **Gerbers** — one file per manufacturing layer | To order boards |
| `*.drl` | **Drill file** — hole positions and sizes | To order boards |
| `*Fab Output*.zip` | Gerbers + drill, zipped and ready to upload | **This is the one you send a factory** |

The `.net` file is genuinely readable in a text editor. If you only want to know
which GPIO a connector pin goes to, open it and search — you do not need KiCad
installed at all.

---

## 2. Just re-order a board, unchanged

**You do not need KiCad for this.** Upload the fab zip and pick options.

| Board | Zip to upload | Size |
|---|---|---|
| Wheel Drive | `KiCad/Wheel Drive PCB/Wheel Drive Fab Output/` *(zip the folder)* | 130 × 105 mm |
| Driver ×4 | `KiCad/Driver PCB/Driver_PCB_fabrication.zip` | 42.8 × 33.8 mm |
| Arm Subsystem | `KiCad/Arm Subsystem PCB/Arm Fab Output.zip` | 110 × 110 mm |

Order settings that match what was built: **2 layers, 1.6 mm thickness, 1 oz
copper, HASL finish.** Nothing here needs impedance control, blind vias or any
other paid option.

**Order at least 5 Driver PCBs** even though the robot needs 4 — they are the
cheapest board and the most likely to be damaged, and minimum order is usually 5
anyway.

---

## 3. Opening the projects

Install **KiCad 9.0.6 or newer** (these were made in 9.0.6). Open the
`.kicad_pro` file.

### What will and will not work

The schematic caches every symbol it uses inside the `.kicad_sch`, and the layout
stores complete footprint definitions inside the `.kicad_pcb`. So:

✅ **Opening, reading, printing and re-exporting gerbers all work perfectly**
with no libraries installed.

⚠️ **Three libraries are referenced but are not in this repo**, and you will hit
them the moment you try to *add* one of those parts or run **Tools → Update PCB
from Schematic**:

| Library | Contains | Getting it back |
|---|---|---|
| `PCM_Espressif` | `ESP32-S3-DevKitC` symbol | Install from KiCad's **Plugin and Content Manager** — it is Espressif's official library. Easy |
| `My_30.007_Library` | `VL53L0X_breakout_(Kuriosity)` symbol | **Custom.** Recreate, or ask the original authors |
| `HengLi's Footprint Library` | `ESP32-S3-DevKitC-N16R8` footprint | **Custom** (Heng Li). Recreate, or ask |

**[VERIFIED]** — no `.pretty` folder, `fp-lib-table` or `sym-lib-table` exists
anywhere in this repo.

**What this means practically:** the boards can be reproduced indefinitely and
small layout edits are possible. Schematic→layout re-sync is unavailable until
the two custom libraries are rebuilt. For scale: the DevKitC footprint is two
1×22 headers 22.86 mm apart, so recreating it is an afternoon's work rather than
a project.

---

## 4. Making a change

The loop is always the same:

1. Edit the **schematic** (`.kicad_sch`).
2. **Tools → Update PCB from Schematic** — pushes new connections into the
   layout as unrouted "ratsnest" lines. *(This is the step that needs the
   libraries above.)*
3. Move footprints, route the new tracks in the **layout**.
4. **Inspect → Design Rules Checker (DRC)** — must come back clean.
5. **File → Fabrication Outputs → Gerbers**, and separately **Drill Files**.
6. Zip them. That is your new order.
7. **Re-export the netlist too** (`File → Export → Netlist`) and commit it —
   `boards.md` and `pins.h` are both derived from it, and a stale netlist is how
   this project got a GPIO map that drove the I²C bus as motor enables.

> **If you change a GPIO, you have changed a contract.** `include/pins.h` mirrors
> the netlist and `boards.md` documents it. Update both in the same commit as the
> board change, or the next person will trust the wrong one. The header at the
> top of `pins.h` says "if the board is respun, re-extract rather than
> hand-editing" — follow that.

---

## 5. Assembly notes

### Order of soldering

Shortest parts first, so the board sits flat on the bench:

1. Resistors (Driver PCB)
2. Transistors — **watch the orientation**, see below
3. Pin headers
4. Terminal blocks
5. Female sockets for the DevKit **last**

### The one orientation that will bite you

The Driver PCB's transistor footprint is **TO-92 Inline Wide, E-B-C**, and the
silkscreen prints `E`, `B`, `C` next to the pads. Match the flat face of the
part to the flat side on the silk.

> ⚠️ **2N3904 is E-B-C. BC547 is C-B-E.** Identical packages, mirrored pinouts.
> The board expects a 2N3904. If all you have is BC547, it works only rotated
> 180° — which means the legs must be crossed, not just the body turned. Pick one
> type and stay with it across all four boards. Getting this wrong produces a
> driver that sits happily idle showing a **green** LED, because from its point
> of view it was simply told to stop — see the diagnostic table in `boards.md` §2.

### Socket the DevKits

Both boards take 2× 1×22 female headers for the ESP module. **Do not solder the
DevKit down.** It is the part most likely to need swapping and the one most
easily destroyed during removal.

### Do not fit the encoder connectors

J1/J2, J10/J11, J13/J15, J16/J18 on the Wheel Drive PCB are for the abandoned
AS5600 encoders. Leaving them unpopulated saves 28 solder joints and removes any
chance of something being plugged into GPIO1/2/3/14 by accident. `boards.md` §1.

---

## 6. Repair

### Intermittent signal — clean before you desolder

**[OBSERVED — Bryan]** A control line that works, stops, and works again is
usually **flux residue between the traces**, not a failed component. Old
no-clean flux absorbs moisture and oxidises, and at the microamp currents these
adapters run at, the leakage across a 200 µm gap is enough to matter.

**Isopropyl alcohol, a stiff brush, scrub between the traces, dry thoroughly.**
Do this first, every time. It is the cheaper hypothesis and it is usually the
right one.

### Localise a dead motor channel in one minute

Two measurements on the Driver PCB, both safe (microamps throughout):

| Measurement | Healthy | Faulty |
|---|---|---|
| base → COM, GPIO driven high | **~0.7 V** | 1.678 V — junction not conducting |
| collector → COM, enabled vs disabled | large change | 1.069 → 0.945 V — barely moves |

A base that will not clamp at ~0.7 V means the base–emitter path to COM is
broken. A collector that does not move means the transistor is not switching.

### Swap-test before you theorise

All four Driver PCBs are identical and all four `J4`–`J7` outputs are identical
in form. Move a suspect board to a known-good wheel's output: if the fault
follows the board it is the board; if it stays with the wheel it is the driver,
the motor, or the loom. **This is faster than any measurement** and it needs no
equipment.

---

## 7. Before you power a board you just built

- [ ] **Continuity: every ground pin to every other ground pin.**
- [ ] **No continuity between 3V3 and GND.** A short here with the DevKit fitted
      kills the DevKit's regulator.
- [ ] Transistor orientation matches the `E`/`B`/`C` silkscreen.
- [ ] DevKit sockets are the right way round — pin 1 is the **square pad**.
- [ ] Wheel Drive **J3 wired to the motor supply ground** before anything is
      switched on (`startup.md` §2).

Note there is **no power input** on either ESP board — `3V3` is generated by the
DevKit and flows *outward* to the sensors. So the first power-on is simply
plugging the DevKit's USB in, and the 3V3-to-GND short check above is your only
chance to catch a fault before the DevKit's regulator finds it for you. Do it
with a meter, on the empty socket, before the module goes in.

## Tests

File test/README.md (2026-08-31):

# test/ — host unit tests

One suite per domain module (Unity framework). They run on the laptop against
[`lib/fakes/`](../lib/fakes/) — no hardware needed:

```bash
pio test -e native
```

Covered: corner edge detection, dead-reckon odometry, docking state machine,
safety monitor, stall detector, link watchdog, mecanum mixing, motor-cal analysis.

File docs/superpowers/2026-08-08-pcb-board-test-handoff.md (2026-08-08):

# Handoff — Wheel Drive PCB board testing (2026-08-08)

Pick up here. Everything below is committed and builds.

## Where things stand

The RL corner of the fabricated Wheel Drive PCB is working: motor spins both
directions under `env:pcb_rl`, driven from the pin map in `include/pins.h`.
A production test loop exists for qualifying the rest of the manufactured boards.

**Immediate next step:** the ESP needs one more flash of `env:pcb_rl` (the
`setTxTimeoutMs(0)` fix). At handoff the chip was wedged and refusing to sync;
a USB replug clears it, then:

```
pio run -e pcb_rl -t upload
python3 tools/board_test.py
```

## The tooling

| File | What it does |
|---|---|
| `src/bench_pcb_rl.cpp` | RL bring-up + full-board signal scan. Reads `pins.h`, never a hand-typed table. |
| `tools/board_test.py` | Per-board loop: boot check, signal scan vs golden, motion test, CSV log. |
| `tools/golden_signature.json` | 16-line reference signature. Delete to re-baseline. |
| `tools/board_test_log.csv` | Per-board results. |

Firmware commands: `t` self-test, `s` signal scan, `w` meter walk, `e/+/-/d/b`
manual, space to stop, `?` help.

### Why the golden-signature approach

Absolute pin readings cannot be judged on their own. A populated transistor
adapter loads the pin — its ~100k base pulldown against the ESP's ~45k internal
pull-up divides to ~2.3 V, below the S3's input-high threshold — so a perfectly
good adapter channel reads "held low". The first board scanned becomes the
reference and every later board is diffed against it, which cancels the loading.

Current golden shows RL.F/R, RL.EN, RL.BRK loaded (RL is the only corner with
adapters fitted) and the other 13 lines floating. Fit FL's adapters and those
rows shift the same way — the scan doubles as a check of which channels are
populated.

### Scan limits

- Sees the **ESP side only**: pin, trace, adapter input. Not the adapter output
  or the header wiring to the driver.
- Detects shorts and bridges. **Cannot detect an open trace** — the chip cannot
  sense a wire going nowhere. Opens need `w` plus a meter at the header.
- `s` pulses 3 ms per pin so it is safe either way, but `w` holds each line
  asserted for 4 s. Run `w` with 24 V OFF.

## Results so far

| Board | Result |
|---|---|
| 1 | PASS — both directions |
| 2 | FAIL — reverse only |
| 3 | FAIL — no motion |
| 4 | FAIL, then PASS on retest |

Treat the FAILs as provisional. Several were recorded while the wedge bug was
active, and "reverse only" may not be a fault at all — see below.

## Open items

- [ ] **"Reverse only" may be a false failure.** `bench_pcb_rl.cpp` has NO invert
      table; it drives F/R raw. RL is a left-hand corner, and the bench
      calibration found left motors mounted mirrored (`g_bld_invert =
      {true,false,true,false}`). A board turning "reverse only" may be behaving
      identically to board 1. Re-test boards 2 and 4 before scrapping anything.
- [ ] **Re-test every board** once the `setTxTimeoutMs(0)` firmware is flashed.
- [ ] **GPIO0 on the PCB** — root-caused to a missing ESP↔PSU ground, fixed by
      wiring it. Confirm it stays fixed across boards.
- [ ] **FR and RL pin order** — `bench_bld_drive.h` and `pins.h` disagree: the
      four roles are in opposite order for those two corners. The breadboard rigs
      must never be pointed at the fabricated PCB. Reconcile or delete one.
- [ ] **`Serial.setTxTimeoutMs(0)` belongs in `main.cpp` too.** A Pi that stops
      draining the link must not be able to stall the ESP's control loop — same
      principle as `LinkWatchdog`, one layer down. Not yet done.
- [ ] Extend the motion test beyond RL once FL/FR/RR adapters are fitted.
- [ ] `max_lin_mm_s = 300` in `config.h` is still wrong by several times.

## Traps, in one place

1. **Open serial ports with DTR and RTS LOW.** DTR is the IO0 strap on
   USB-Serial-JTAG; asserting it forces download mode. A probe that sets
   `dtr=True` wedges the board and then reports it as silent.
2. **A silent board is usually a wedged USB session, not a fault.** Unplug and
   replug. `tools/board_test.py` now detects this and retries.
3. **`boot:0x3` means the app never ran** — GPIO0 low at reset. No amount of
   motor debugging will help until it reads `boot:0x8`.
4. **`digitalWrite` before `pinMode` is rejected** on Arduino-ESP32 3.x. Boot
   safety comes from the adapter polarity (latch resets LOW = released), not
   from write ordering. See the warning in `lib/hal_esp32/Bld120aMotor.h`.

Full detail on 1–3 in `docs/hardware-architecture.md`, "Bring-up gotchas".

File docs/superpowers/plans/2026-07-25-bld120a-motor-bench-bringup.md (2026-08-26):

# BLD-120A Motor Bench Bring-up — Handoff Plan

> **Cold-start handoff.** This was written because the chat history is being
> reset. It is self-contained: a fresh agent (or Bryan) should be able to pick
> up the bench work from here with no prior conversation. Read it top to bottom
> before touching hardware.

**Goal:** Validate the **BLD-120A** BLDC driver's control interface (SV / F-R /
EN / BRK) on the bench, driven by a **plain ESP32-WROOM-32D devkit**, before
trusting the 4-motor wiring on the production S3 board (`include/pins.h`).

**Status as of 2026-07-25:** firmware written, built, flashed, and the console
+ safety interlock are verified on hardware. **The motor has NOT been spun by
the agent** — enabling the driver is a hands-on-the-PSU step left to Bryan.

---

## What exists (files)

| File | State | Purpose |
|---|---|---|
| `src/bench_motor.cpp` | **new, untracked** | The bench firmware. Single motor, serial-console control. |
| `platformio.ini` → `[env:bench_motor]` | **new, modified** | Build env. `board = esp32dev`, CH340 UART, `SerialCommands` dep. |
| `bench_motor_test/bench_motor_test.ino` | **untracked, SUPERSEDED** | Old Arduino-IDE sketch this replaced. Safe to delete once `src/bench_motor.cpp` is trusted. Not deleted yet in case Bryan still flashes it from the IDE. |

Build/flash/monitor:
```bash
pio run -e bench_motor -t upload && pio device monitor -e bench_motor
```

Both `platformio.ini` and `src/bench_align.h` also show as modified in git from
**earlier, unrelated** work — do not assume those `bench_align.h` changes are
part of this task.

---

## Hardware

- **MCU:** ESP32-WROOM-32D devkit. Chip verified on the wire via esptool:
  **ESP32-D0WD rev v1.0**, MAC `4c:11:ae:b3:9c:18`, on `/dev/cu.wchusbserial310`
  (CH340 UART bridge — NOT native USB, so **no** `ARDUINO_USB_CDC_ON_BOOT`).
  This is a *different board* from every other env in the repo (the S3s).
- **Driver:** BLD-120A "BLDC MOTOR DRIVER RUN/ALM", 12–30 V. Terminal order on
  the green block, left→right:
  `BRK EN F/R COM SV REF+ HU HV HW REF- W V U DC+ DC-`
- **Motor supply:** external **24 V** bench PSU on DC+/DC-, on its own. ESP on
  USB. **Never bridge the two grounds except through COM** (see wiring).
- **Second BLD-120A** sits on the same red 24 V rail but has **no control
  wires** → its EN floats high → it stays disabled. Harmless, but don't
  attribute a spin to the wrong driver.

### Verified wiring (colour map, confirmed from photo 2026-07-23)

The five control wires descend in a clean, non-crossing bundle in the same
order as the first five driver terminals:

| Wire colour | ESP pin | Driver terminal | Firmware constant |
|---|---|---|---|
| brown | GPIO18 | BRK (1) | `PIN_BRK` |
| red | GPIO17 | EN (2) | `PIN_EN` |
| orange | GPIO16 | F/R (3) | `PIN_FR` |
| black | GND | COM (4) | signal ground |
| white | GPIO25 | SV (5) | `PIN_SV` (DAC1) |

**Confidence:** the ESP end is Bryan's statement; the driver end is inferred
from wire *order* in the photo, not from seeing each conductor seated in its
screw terminal. **A continuity beep from each ESP header pin to its driver
terminal is the cheap way to remove all doubt** — see Task 1.

- **GPIO25 = DAC1.** Firmware defaults to true analog DC out (`dacWrite`), not
  PWM. `SV_USE_DAC 0` switches it back to 1 kHz LEDC PWM (matches production).
- GPIO16/17 are free here because WROOM-32D has **no PSRAM** (they'd be
  reserved on a WROVER/S3). GPIO2 (onboard LED heartbeat) is a strapping pin —
  fine to drive, just never hang a pull-up off it.

---

## Firmware behaviour (`src/bench_motor.cpp`)

- **Console library:** `ppedro74/SerialCommands` (already a repo dependency —
  library-first, no hand-rolled parser). One-key commands dispatch on the FIRST
  character, **before any Enter**, so the `x` E-STOP fires on keypress. This is
  the whole reason for the library and matters on a spinning motor.
- **Commands:**
  - instant (no Enter): `e`/`d` enable/disable · `f`/`r` fwd/rev ·
    `b`/`n` brake on/off · `+`/`-` nudge ±8 · `x` E-STOP · `?` help+status
  - with Enter: `s <0-255>` set command · `v <volts>` set by SV volts ·
    `sweep` auto-ramp 0→max→0
- **Boots SAFE:** disabled, forward, no brake, command 0.
- **Safety interlock (verified):** SV is gated on `(g_enabled && !g_brake)` in
  the control tick. A stale `s 60` cannot leak onto the driver until `e`.
  Confirmed on hardware: `s 60` set target 60/255 but status kept showing
  `cmd 0/255 → 0.00V` while disabled.
- **Slew limiter:** `SLEW_STEP` units/tick soft-ramps SV; `x` collapses it to 0
  immediately (no ramp-down on E-STOP).
- **Control lines are OUTPUT_OPEN_DRAIN** by default: asserting = pull to COM,
  releasing = Hi-Z (driver's internal pull-up holds high). `PUSH_PULL_CTRL 1`
  switches to plain 3.3 V push-pull.
- **Polarity constants carry Bryan's CONFIRMED-2026-07-15 values**, unverified
  by the agent this session: `EN_ASSERT=LOW`, `FR_FWD=HIGH`, `BRK_ASSERT=LOW`.
  Flip the relevant constant if a line behaves inverted.

---

## KNOWN LIMITATION — the 3.3 V ceiling (unresolved)

SV wants **0–5 V**; the ESP sources only **0–3.3 V**. Worse, SV is a pot-wiper
input that loads the source down: bench-measured **2.59 V at full command**
(2026-07-15) ≈ **~52 %** of the driver's 0–5 V span. **This rig therefore
cannot reach top speed.** It is fine for validating polarity / ramp / brake,
not for characterising the motor's top end.

**Library-first fix when full span is needed:**
- an **MCP4725** I2C DAC run off 5 V (`adafruit/Adafruit MCP4725`), or
- a non-inverting op-amp ×1.5 buffer on GPIO25.

A `HAS_SV_SENSE` block (default off) is already wired in the firmware: SV
through a 10 k/10 k divider into GPIO34 (ADC1, input-only, 5 V-safe) so you can
print what the driver ACTUALLY sees vs what was commanded.

---

## Open safety items (do these BEFORE enabling)

1. **THERE IS NO CURRENT PROTECTION AND NO SOFTWARE FAULT TRIP.**
   *Corrected 2026-07-27 — an earlier version of this document told you to set a
   ~1 A PSU current limit and called it "the only safety net". **The bench PSU has
   no current limit at all.** Do not rely on that instruction.*

   The BLD-120A has **no ALM output / no FG** (the "RUN/ALM" and "Peak Power" /
   "P-sv" markings on the case top are silkscreen *artwork*, not readable pot
   positions). The actual protection chain is: the driver's "Peak Power" trim
   (≤8 A, position unverified within its 0.8–8.0 A range), then a **10 A fuse**
   to the driver. Nothing else.

   Free-running at no load (~0.2–1 A) is not the concern. **Stall is:** a locked
   rotor held at the driver's limit sinks up to 8 A at 24 V = **192 W**, nearly
   all of it into stationary windings. The 10 A fuse cannot help — an 8 A stall
   sits below it indefinitely, so it never opens while the motor cooks. The fuse
   protects the cable, not the load.

   Mitigation is now software: the AS5600 added 2026-07-27 makes a genuine stall
   trip possible for the first time (command above break-away + RPM at zero →
   cut SV, brake, abort). See
   `docs/superpowers/specs/2026-07-27-bld120a-motor-calibration-design.md`.
   Until that ships, **do not leave the rig running unattended.**
2. **EN/F-R/BRK idle voltage unverified.** The open-drain config assumes the
   driver's internal pull-up idles at 3.3 V-safe levels. **With 24 V on and the
   ESP unplugged, probe EN / F/R / BRK against COM.** If they idle at **5 V**,
   they back-feed the ESP's clamp diodes on release (survivable ~0.1 mA, but out
   of spec) → add level shifting rather than trusting the clamps.

---

## Next steps (task list)

- [ ] **Task 1 — Verify wiring.** Continuity-beep each ESP header pin
      (GPIO18/17/16/GND/25) to its driver terminal (BRK/EN/F-R/COM/SV). Confirms
      the inferred colour map and rules out a brown↔red swap (which would make
      `e` brake and `b` enable).
- [ ] **Task 2 — Probe idle levels** (safety item 2 above).
- [x] **Task 3 — First spin.** DONE 2026-07-27: wheel turned and braked. (The
      "set PSU current limit LOW" precondition was void — there is no PSU current
      limit; see safety item 1.) Sequence used:
      `pio device monitor -e bench_motor` →
      `?` (confirm `EN:off cmd:0/255`) → `f` → `e` (motor live) → `s 60`
      (~0.78 V, should just break away) → `+` to nudge up → `x` to stop.
      **If `s 60` does nothing, suspect the driver's onboard P-sv trim is turned
      down — rule that out before blaming the 3.3 V ceiling.**
- [ ] **Task 4 — Confirm/flip polarity constants** (`EN_ASSERT`, `FR_FWD`,
      `BRK_ASSERT`) against observed behaviour; update the CONFIRMED date.
- [ ] **Task 5 (optional) — Recover full SV span** via MCP4725 or op-amp buffer
      (see Known Limitation), then enable `HAS_SV_SENSE` to close the loop on
      commanded-vs-measured SV.
- [ ] **Task 6 — Cleanup.** Once `src/bench_motor.cpp` is trusted, delete the
      superseded `bench_motor_test/` sketch and commit both new files.

---

## Provenance / prior facts pulled in

- Memory `falali-bld120a-driver`: real driver has NO FG/ALM; COM = signal
  gnd; F/R high = fwd; EN low = enable; 12–30 V.
- Memory `falali-bench-ble-gamepad`: 12 V killed an ESP once → the ~7.5 V
  rail note is for the *L298N mecanum* rig, NOT this BLD-120A rig (this one is
  correctly on its own 24 V PSU with isolated grounds).
- Bench log 2026-07-15: proportional ramp 0.78→2.59 V SV, F/R reversal, EN
  enable all validated on hardware — this firmware is a cleaner re-implementation
  of that same known-good behaviour.

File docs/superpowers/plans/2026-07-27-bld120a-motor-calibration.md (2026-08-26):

# BLD-120A Motor Calibration Implementation Plan

> **For agentic workers:** REQUIRED SUB-SKILL: Use superpowers:subagent-driven-development (recommended) or superpowers:executing-plans to implement this plan task-by-task. Steps use checkbox (`- [ ]`) syntax for tracking.

**Goal:** Add three calibration routines (`calsweep`, `calstep`, `calgear`) to the BLD-120A bench firmware, plus a mandatory stall trip, so the motor's SV→RPM curve, step response, and gearbox ratio become measured numbers.

**Architecture:** Analysis math and the stall trip go in `lib/domain/` as pure C++17 classes with host unit tests (matching the repo's existing hexagonal split). `src/bench_motor.cpp` gains three non-blocking state machines driven from `loop()` that own timing and I/O only. No `delay()` anywhere — a blocking loop would kill the `x` e-stop for minutes.

**Tech Stack:** PlatformIO, Arduino-ESP32 core 3.2.1, `ppedro74/SerialCommands`, `robtillaart/AS5600` 0.6.7, Unity (host tests via `[env:native]`).

Spec: `docs/superpowers/specs/2026-07-27-bld120a-motor-calibration-design.md`

## Global Constraints

- Target board is **ESP32-WROOM-32D** (`[env:bench_motor]`, `board = esp32dev`). Not the S3. I2C is **GPIO21/22**, never the 38/39 in `include/pins.h`.
- Gearbox ratio is **15:1**. Encoder is **4096 cpr** on the **motor output shaft**. Motor counts per wheel revolution = **61440**.
- Directions are **driver-frame only**: label `FR=HIGH` / `FR=LOW`. Never emit "forward"/"reverse" — chassis orientation is unconfirmed.
- **`x` must abort at any point, from any state.** Every routine is a state machine polled from `loop()`; `delay()` is forbidden in routine code.
- **Stall detection is armed for the entire run** and no routine may disable it, including during Phase 2's deliberate stop captures.
- Routines refuse to start while the brake is latched (`x` sets `g_brake` with no auto-clear) and must say why.
- Pure C++17 in `lib/domain/`: no Arduino headers, `namespace fal`, `#pragma once`, trailing-underscore privates.
- CSV rows are prefixed `CSV,` so they can be grepped out of the interleaved 2 Hz status stream.
- Host tests run with `pio test -e native`. Firmware builds with `pio run -e bench_motor`.

---

### Task 1: StallDetector (pure, host-tested)

Safety-critical and entirely time/threshold logic, so it is built and tested with zero hardware.

**Files:**
- Create: `lib/domain/StallDetector.h`
- Create: `lib/domain/StallDetector.cpp`
- Test: `test/test_stall_detector/test_stall_detector.cpp`

**Interfaces:**
- Consumes: nothing (first task)
- Produces: `fal::StallConfig{ int break_away_cmd; float rpm_floor; uint32_t trip_ms; uint32_t grace_ms; }`, `fal::StallDetector` with `void reset(uint32_t now_ms)`, `void noteCommandIncrease(uint32_t now_ms)`, `bool update(uint32_t now_ms, int cmd, float rpm)` returning true on the trip edge, `bool tripped() const`, `int trippedAtCmd() const`

- [ ] **Step 1: Write the failing test**

Create `test/test_stall_detector/test_stall_detector.cpp`:

```cpp
// Host tests for StallDetector — the software fault trip that replaces the
// bench's missing current limit. The BLD-120A has no ALM output, so this is
// the rig's only automatic protection against a locked rotor at 192 W.
#include <unity.h>

#include "StallDetector.h"

using namespace fal;

void setUp() {}
void tearDown() {}

static StallConfig cfg() {
  StallConfig c;
  c.break_away_cmd = 40;
  c.rpm_floor = 5.0f;
  c.trip_ms = 250;
  c.grace_ms = 300;
  return c;
}

void test_no_trip_below_break_away() {
  // Below break-away the motor is EXPECTED to be still. Zero RPM is not a fault.
  StallDetector d(cfg());
  d.reset(0);
  for (uint32_t t = 0; t <= 2000; t += 50) {
    TEST_ASSERT_FALSE(d.update(t, 20, 0.0f));
  }
  TEST_ASSERT_FALSE(d.tripped());
}

void test_trips_when_commanded_but_not_turning() {
  StallDetector d(cfg());
  d.reset(0);
  bool edge = false;
  for (uint32_t t = 0; t <= 1000; t += 50) {
    if (d.update(t, 100, 0.0f)) edge = true;
  }
  TEST_ASSERT_TRUE(edge);
  TEST_ASSERT_TRUE(d.tripped());
  TEST_ASSERT_EQUAL_INT(100, d.trippedAtCmd());
}

void test_no_trip_while_turning() {
  StallDetector d(cfg());
  d.reset(0);
  for (uint32_t t = 0; t <= 2000; t += 50) {
    TEST_ASSERT_FALSE(d.update(t, 100, 800.0f));
  }
}

void test_grace_period_suppresses_trip_after_command_increase() {
  // Accelerating from rest must not read as a stall.
  StallDetector d(cfg());
  d.reset(0);
  d.noteCommandIncrease(0);
  // 250ms of zero RPM would normally trip, but we are inside the 300ms grace.
  for (uint32_t t = 0; t <= 280; t += 20) {
    TEST_ASSERT_FALSE(d.update(t, 100, 0.0f));
  }
}

void test_trips_after_grace_expires() {
  StallDetector d(cfg());
  d.reset(0);
  d.noteCommandIncrease(0);
  bool edge = false;
  for (uint32_t t = 0; t <= 1200; t += 20) {
    if (d.update(t, 100, 0.0f)) edge = true;
  }
  TEST_ASSERT_TRUE(edge);
}

void test_negative_rpm_counts_as_turning() {
  // FR=LOW spins the other way; magnitude is what matters, not sign.
  StallDetector d(cfg());
  d.reset(0);
  for (uint32_t t = 0; t <= 2000; t += 50) {
    TEST_ASSERT_FALSE(d.update(t, 100, -800.0f));
  }
}

void test_trip_edge_fires_once() {
  StallDetector d(cfg());
  d.reset(0);
  int edges = 0;
  for (uint32_t t = 0; t <= 2000; t += 50) {
    if (d.update(t, 100, 0.0f)) edges++;
  }
  TEST_ASSERT_EQUAL_INT(1, edges);
}

void test_reset_clears_trip() {
  StallDetector d(cfg());
  d.reset(0);
  for (uint32_t t = 0; t <= 1000; t += 50) d.update(t, 100, 0.0f);
  TEST_ASSERT_TRUE(d.tripped());
  d.reset(2000);
  TEST_ASSERT_FALSE(d.tripped());
}

void test_recovery_restarts_the_window() {
  // Motor briefly turns, then stalls. The 250ms window restarts on motion,
  // so a momentary stall shorter than trip_ms must not accumulate.
  StallDetector d(cfg());
  d.reset(0);
  TEST_ASSERT_FALSE(d.update(0,   100, 0.0f));
  TEST_ASSERT_FALSE(d.update(200, 100, 0.0f));   // 200ms stalled, under 250
  TEST_ASSERT_FALSE(d.update(240, 100, 900.0f)); // turning again -> window resets
  TEST_ASSERT_FALSE(d.update(400, 100, 0.0f));   // only 160ms since restart
  TEST_ASSERT_FALSE(d.tripped());
}

int main(int, char**) {
  UNITY_BEGIN();
  RUN_TEST(test_no_trip_below_break_away);
  RUN_TEST(test_trips_when_commanded_but_not_turning);
  RUN_TEST(test_no_trip_while_turning);
  RUN_TEST(test_grace_period_suppresses_trip_after_command_increase);
  RUN_TEST(test_trips_after_grace_expires);
  RUN_TEST(test_negative_rpm_counts_as_turning);
  RUN_TEST(test_trip_edge_fires_once);
  RUN_TEST(test_reset_clears_trip);
  RUN_TEST(test_recovery_restarts_the_window);
  return UNITY_END();
}
```

- [ ] **Step 2: Run test to verify it fails**

Run: `pio test -e native -f test_stall_detector`
Expected: FAIL — compile error, `StallDetector.h` not found.

- [ ] **Step 3: Write minimal implementation**

Create `lib/domain/StallDetector.h`:

```cpp
// The bench rig's only automatic fault protection.
//
// The BLD-120A exposes no ALM output and no FG, and the bench PSU has no current
// limit — so before the AS5600 was fitted there was literally no signal from which
// a stall could be inferred. A locked rotor held at the driver's limit sinks up to
// 8 A at 24 V (~192 W) into stationary windings, and the 10 A fuse never opens
// because 8 A sits below it indefinitely.
//
// The trip keys on the actual fault — "commanded to move, not moving" — rather
// than on current, so it does not false-trip on legitimate inrush.
#pragma once

#include <stdint.h>

namespace fal {

struct StallConfig {
  // Below this command the motor is expected to be still, so zero RPM is normal
  // rather than a fault. Set from the measured break-away point.
  int      break_away_cmd = 40;
  float    rpm_floor      = 5.0f;   // |RPM| under this counts as "not turning"
  uint32_t trip_ms        = 250;    // sustained stall before tripping
  uint32_t grace_ms       = 300;    // suppression after a command increase
};

class StallDetector {
public:
  StallDetector() = default;
  explicit StallDetector(const StallConfig& cfg) : cfg_(cfg) {}

  // Clears the trip and restarts all timing. Call before every routine.
  void reset(uint32_t now_ms);

  // Opens a grace window. Call whenever the command steps UP, so ordinary
  // acceleration from rest is not mistaken for a locked rotor.
  void noteCommandIncrease(uint32_t now_ms);

  // Returns true ONCE, on the transition into the tripped state.
  bool update(uint32_t now_ms, int cmd, float rpm);

  bool tripped() const { return tripped_; }
  int  trippedAtCmd() const { return tripped_at_cmd_; }

private:
  StallConfig cfg_{};
  bool     tripped_        = false;
  int      tripped_at_cmd_ = 0;
  bool     stalling_       = false;  // currently inside a candidate stall
  uint32_t stall_since_    = 0;
  uint32_t grace_until_    = 0;
};

} // namespace fal
```

Create `lib/domain/StallDetector.cpp`:

```cpp
#include "StallDetector.h"

namespace fal {

static inline float absf(float v) { return v < 0.0f ? -v : v; }

void StallDetector::reset(uint32_t now_ms) {
  tripped_ = false;
  tripped_at_cmd_ = 0;
  stalling_ = false;
  stall_since_ = now_ms;
  grace_until_ = now_ms;
}

void StallDetector::noteCommandIncrease(uint32_t now_ms) {
  grace_until_ = now_ms + cfg_.grace_ms;
  stalling_ = false;  // restart the window; the motor is being asked to speed up
}

bool StallDetector::update(uint32_t now_ms, int cmd, float rpm) {
  if (tripped_) return false;  // edge already delivered

  // Not commanded hard enough to expect motion -> nothing to police.
  if (cmd < cfg_.break_away_cmd) { stalling_ = false; return false; }

  // Inside the post-step grace window -> acceleration, not a stall.
  if ((int32_t)(now_ms - grace_until_) < 0) { stalling_ = false; return false; }

  const bool moving = absf(rpm) >= cfg_.rpm_floor;
  if (moving) { stalling_ = false; return false; }

  if (!stalling_) { stalling_ = true; stall_since_ = now_ms; return false; }

  if (now_ms - stall_since_ >= cfg_.trip_ms) {
    tripped_ = true;
    tripped_at_cmd_ = cmd;
    return true;
  }
  return false;
}

} // namespace fal
```

- [ ] **Step 4: Run test to verify it passes**

Run: `pio test -e native -f test_stall_detector`
Expected: PASS, 9 tests.

- [ ] **Step 5: Commit**

```bash
git add lib/domain/StallDetector.h lib/domain/StallDetector.cpp test/test_stall_detector/test_stall_detector.cpp
git commit -m "feat(bench): add StallDetector — software fault trip for the BLD-120A rig"
```

---

### Task 2: MotorCalAnalysis (pure, host-tested)

All the curve arithmetic. Kept out of the firmware so it can be tested against synthetic data with known answers.

**Files:**
- Create: `lib/domain/MotorCalAnalysis.h`
- Create: `lib/domain/MotorCalAnalysis.cpp`
- Test: `test/test_motor_cal_analysis/test_motor_cal_analysis.cpp`

**Interfaces:**
- Consumes: nothing
- Produces: `fal::CalPoint{ int cmd; float sv_volts; float rpm; }`, `fal::LinearFit{ float slope_rpm_per_volt; float intercept_rpm; bool valid; }`, and free functions `LinearFit fitLinear(const CalPoint*, size_t)`, `int breakAwayCmd(const CalPoint*, size_t, float)`, `int dropOutCmd(const CalPoint*, size_t, float)`, `int kneeCmd(const CalPoint*, size_t, const LinearFit&, float, float)`, `float gearRatio(int32_t, float, int32_t)`

- [ ] **Step 1: Write the failing test**

Create `test/test_motor_cal_analysis/test_motor_cal_analysis.cpp`:

```cpp
// Host tests for the motor calibration arithmetic, fed synthetic curves with
// known answers. The bench measured 1012 RPM/V on 2026-07-27, so that slope is
// used as the realistic case throughout.
#include <unity.h>

#include "MotorCalAnalysis.h"

using namespace fal;

void setUp() {}
void tearDown() {}

// Synthetic curve: 1012 RPM/V, dead below cmd 40, 33 points at cmd = i*8 (cap 255).
static size_t makeCurve(CalPoint* out, int break_away, float slope) {
  size_t n = 0;
  for (int i = 0; i <= 32; i++) {
    int cmd = i * 8; if (cmd > 255) cmd = 255;
    float v = 3.3f * cmd / 255.0f;
    float rpm = (cmd >= break_away) ? slope * v : 0.0f;
    out[n++] = CalPoint{cmd, v, rpm};
  }
  return n;
}

void test_fit_recovers_known_slope() {
  CalPoint pts[33];
  size_t n = makeCurve(pts, 0, 1012.0f);   // no deadband -> pure line
  LinearFit f = fitLinear(pts, n);
  TEST_ASSERT_TRUE(f.valid);
  TEST_ASSERT_FLOAT_WITHIN(1.0f, 1012.0f, f.slope_rpm_per_volt);
  TEST_ASSERT_FLOAT_WITHIN(1.0f, 0.0f, f.intercept_rpm);
}

void test_fit_invalid_on_too_few_points() {
  CalPoint pts[1] = {{0, 0.0f, 0.0f}};
  TEST_ASSERT_FALSE(fitLinear(pts, 1).valid);
  TEST_ASSERT_FALSE(fitLinear(pts, 0).valid);
}

void test_break_away_is_first_moving_command() {
  CalPoint pts[33];
  size_t n = makeCurve(pts, 40, 1012.0f);
  // cmd steps by 8, so the first point at/after 40 is 40 itself.
  TEST_ASSERT_EQUAL_INT(40, breakAwayCmd(pts, n, 5.0f));
}

void test_break_away_returns_minus_one_when_never_moves() {
  CalPoint pts[33];
  size_t n = makeCurve(pts, 9999, 1012.0f);  // never turns
  TEST_ASSERT_EQUAL_INT(-1, breakAwayCmd(pts, n, 5.0f));
}

void test_drop_out_is_last_moving_command_on_a_down_leg() {
  // Down-leg ordering: highest command first. Drop-out is where it stops.
  CalPoint pts[4] = {
    {100, 1.29f, 1300.0f},
    { 80, 1.03f,  900.0f},
    { 40, 0.52f,   30.0f},
    { 32, 0.41f,    0.0f},
  };
  TEST_ASSERT_EQUAL_INT(40, dropOutCmd(pts, 4, 5.0f));
}

void test_hysteresis_is_break_away_minus_drop_out() {
  // Stiction: it takes more command to start than to keep going.
  CalPoint up[3]   = {{40, 0.52f, 0.0f}, {48, 0.62f, 0.0f}, {56, 0.72f, 600.0f}};
  CalPoint down[3] = {{56, 0.72f, 600.0f}, {48, 0.62f, 480.0f}, {40, 0.52f, 0.0f}};
  int ba = breakAwayCmd(up, 3, 5.0f);
  int dr = dropOutCmd(down, 3, 5.0f);
  TEST_ASSERT_EQUAL_INT(56, ba);
  TEST_ASSERT_EQUAL_INT(48, dr);
  TEST_ASSERT_EQUAL_INT(8, ba - dr);
}

void test_knee_detects_saturation() {
  // Linear to cmd 160, then hard flat — the knee must land at the departure.
  CalPoint pts[5] = {
    { 40, 0.52f,  526.0f},
    { 80, 1.03f, 1042.0f},
    {120, 1.55f, 1569.0f},
    {160, 2.07f, 2095.0f},
    {200, 2.59f, 2100.0f},   // saturated: fit predicts ~2621
  };
  LinearFit f = fitLinear(pts, 4);       // fit only the linear span
  int knee = kneeCmd(pts, 5, f, 5.0f, 5.0f);
  TEST_ASSERT_EQUAL_INT(200, knee);
}

void test_knee_returns_minus_one_when_linear_throughout() {
  CalPoint pts[33];
  size_t n = makeCurve(pts, 0, 1012.0f);
  LinearFit f = fitLinear(pts, n);
  TEST_ASSERT_EQUAL_INT(-1, kneeCmd(pts, n, f, 5.0f, 5.0f));
}

void test_gear_ratio_exact() {
  // 10 wheel revolutions through a 15:1 box at 4096 cpr = 614400 motor counts.
  TEST_ASSERT_FLOAT_WITHIN(0.001f, 15.0f, gearRatio(614400, 10.0f, 4096));
}

void test_gear_ratio_detects_mislabelled_box() {
  // Same counts but only 8 wheel revs observed -> the box is not 15:1.
  float r = gearRatio(614400, 8.0f, 4096);
  TEST_ASSERT_FLOAT_WITHIN(0.01f, 18.75f, r);
}

void test_gear_ratio_zero_revs_is_invalid() {
  TEST_ASSERT_FLOAT_WITHIN(0.001f, 0.0f, gearRatio(614400, 0.0f, 4096));
}

void test_gear_ratio_uses_magnitude() {
  // FR=LOW accumulates negative counts; the ratio is a magnitude.
  TEST_ASSERT_FLOAT_WITHIN(0.001f, 15.0f, gearRatio(-614400, 10.0f, 4096));
}

int main(int, char**) {
  UNITY_BEGIN();
  RUN_TEST(test_fit_recovers_known_slope);
  RUN_TEST(test_fit_invalid_on_too_few_points);
  RUN_TEST(test_break_away_is_first_moving_command);
  RUN_TEST(test_break_away_returns_minus_one_when_never_moves);
  RUN_TEST(test_drop_out_is_last_moving_command_on_a_down_leg);
  RUN_TEST(test_hysteresis_is_break_away_minus_drop_out);
  RUN_TEST(test_knee_detects_saturation);
  RUN_TEST(test_knee_returns_minus_one_when_linear_throughout);
  RUN_TEST(test_gear_ratio_exact);
  RUN_TEST(test_gear_ratio_detects_mislabelled_box);
  RUN_TEST(test_gear_ratio_zero_revs_is_invalid);
  RUN_TEST(test_gear_ratio_uses_magnitude);
  return UNITY_END();
}
```

- [ ] **Step 2: Run test to verify it fails**

Run: `pio test -e native -f test_motor_cal_analysis`
Expected: FAIL — compile error, `MotorCalAnalysis.h` not found.

- [ ] **Step 3: Write minimal implementation**

Create `lib/domain/MotorCalAnalysis.h`:

```cpp
// Arithmetic over a captured SV->RPM sweep. Deliberately free of Arduino and of
// the sweep state machine, so it can be tested on the host against synthetic
// curves whose answers are known in advance.
#pragma once

#include <stddef.h>
#include <stdint.h>

namespace fal {

struct CalPoint {
  int   cmd      = 0;      // 0..255 command
  float sv_volts = 0.0f;   // commanded SV
  float rpm      = 0.0f;   // measured motor-shaft RPM, sign as measured
};

struct LinearFit {
  float slope_rpm_per_volt = 0.0f;
  float intercept_rpm      = 0.0f;
  bool  valid              = false;
};

// Least-squares fit of |rpm| against sv_volts. valid=false if n < 2 or the
// commanded voltage never varies.
LinearFit fitLinear(const CalPoint* pts, size_t n);

// First point (in array order) whose |rpm| reaches rpm_floor. -1 if none.
// On an ascending leg this is break-away.
int breakAwayCmd(const CalPoint* pts, size_t n, float rpm_floor);

// Last point (in array order) whose |rpm| is still at/above rpm_floor. -1 if none.
// On a descending leg this is drop-out. Break-away minus drop-out is stiction.
int dropOutCmd(const CalPoint* pts, size_t n, float rpm_floor);

// First command where |rpm| departs the fit by more than tol_pct. -1 if the
// curve stays linear throughout. Points whose |rpm| is below rpm_floor are
// skipped — a stationary motor below break-away is not a saturation knee.
int kneeCmd(const CalPoint* pts, size_t n, const LinearFit& fit, float tol_pct, float rpm_floor);

// motor_counts / (cpr * wheel_revs). Uses |motor_counts| so FR=LOW works.
// Returns 0 when wheel_revs is 0 (caller treats as invalid).
float gearRatio(int32_t motor_counts, float wheel_revs, int32_t cpr);

} // namespace fal
```

Create `lib/domain/MotorCalAnalysis.cpp`:

```cpp
#include "MotorCalAnalysis.h"

namespace fal {

static inline float absf(float v) { return v < 0.0f ? -v : v; }

LinearFit fitLinear(const CalPoint* pts, size_t n) {
  LinearFit f;
  if (!pts || n < 2) return f;

  float sx = 0, sy = 0, sxx = 0, sxy = 0;
  for (size_t i = 0; i < n; i++) {
    const float x = pts[i].sv_volts;
    const float y = absf(pts[i].rpm);
    sx += x; sy += y; sxx += x * x; sxy += x * y;
  }
  const float nn = (float)n;
  const float denom = nn * sxx - sx * sx;
  if (absf(denom) < 1e-9f) return f;   // no spread in x

  f.slope_rpm_per_volt = (nn * sxy - sx * sy) / denom;
  f.intercept_rpm      = (sy - f.slope_rpm_per_volt * sx) / nn;
  f.valid              = true;
  return f;
}

int breakAwayCmd(const CalPoint* pts, size_t n, float rpm_floor) {
  if (!pts) return -1;
  for (size_t i = 0; i < n; i++)
    if (absf(pts[i].rpm) >= rpm_floor) return pts[i].cmd;
  return -1;
}

int dropOutCmd(const CalPoint* pts, size_t n, float rpm_floor) {
  if (!pts) return -1;
  int last = -1;
  for (size_t i = 0; i < n; i++)
    if (absf(pts[i].rpm) >= rpm_floor) last = pts[i].cmd;
  return last;
}

int kneeCmd(const CalPoint* pts, size_t n, const LinearFit& fit, float tol_pct, float rpm_floor) {
  if (!pts || !fit.valid) return -1;
  for (size_t i = 0; i < n; i++) {
    const float measured = absf(pts[i].rpm);
    if (measured < rpm_floor) continue;           // stationary/deadband, not a knee
    const float predicted = fit.slope_rpm_per_volt * pts[i].sv_volts + fit.intercept_rpm;
    if (predicted <= 0.0f) continue;              // below the useful range
    const float err_pct = 100.0f * (predicted - measured) / predicted;
    if (err_pct > tol_pct) return pts[i].cmd;     // fell short of the line
  }
  return -1;
}

float gearRatio(int32_t motor_counts, float wheel_revs, int32_t cpr) {
  if (wheel_revs == 0.0f || cpr == 0) return 0.0f;
  const float counts = (float)(motor_counts < 0 ? -motor_counts : motor_counts);
  return counts / ((float)cpr * (wheel_revs < 0.0f ? -wheel_revs : wheel_revs));
}

} // namespace fal
```

- [ ] **Step 4: Run test to verify it passes**

Run: `pio test -e native -f test_motor_cal_analysis`
Expected: PASS, 12 tests.

- [ ] **Step 5: Commit**

```bash
git add lib/domain/MotorCalAnalysis.h lib/domain/MotorCalAnalysis.cpp test/test_motor_cal_analysis/test_motor_cal_analysis.cpp
git commit -m "feat(bench): add MotorCalAnalysis — fit, break-away, hysteresis, knee, gear ratio"
```

---
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

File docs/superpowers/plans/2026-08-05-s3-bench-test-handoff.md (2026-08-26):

# ESP32-S3 motor bench — test session handoff

> **Cold-start handoff.** Self-contained: a fresh Claude Code session (or Bryan)
> should be able to pick up the bench work from here with no prior conversation.
> Read §1–§3 before touching hardware.

**Written:** 2026-08-05
**Goal of the session:** get one BLD-120A + motor turning from the ESP32-S3, then
measure **break-away point** and **true top speed** — the two numbers that unblock
everything downstream.

---

## 1. Where things stand

### Working and verified

| | |
|---|---|
| `bench_s3` firmware | flashed, responds to `?`, boots safe (disabled / no brake / 0%) |
| Slew limiter + interlock | verified in the log — SV gated on `enabled && !brake` |
| Serial | `/dev/cu.wchusbserial5B8F0947541` on the **Mac**, 115200, CH343 bridge |
| Logging | `teleop.py --log` writes CSV + raw to `bench_logs/` |
| Host unit tests | 8 suites, 68 tests, green under `-Wall -Wextra -Werror` |

### ✅ RESOLVED 2026-08-05 — motor turns under full EN/BRK/F-R control

**Root cause: the adapter transistors were miswired** — C and E swapped, and the
100 kΩ pulldown on the collector instead of the base. See
`docs/hardware-architecture.md` §4 for the before/after and the diagnostic
signature. Nothing was damaged; the same transistors were reused.

Confirmed working with the EN jumper **removed**, so the safety chain
(`SafetyMonitor`, `safeStop()`, `LinkWatchdog`) has real authority again.

Full chain verified: Mac → ESP32-S3 → transistor adapter → BLD-120A → motor.
The adapter design and the transistor orientation are **good**.

Three things changed between the failing run and the working one. **Which one was
decisive is not yet known** — worth establishing before building adapters 2–4:

1. **BRK was latched on.** `x` E-STOP sets the brake and `teleop.py` fires `x` on
   exit, so a stale brake survives across sessions. The status line now names the
   blocker explicitly (`<-- BLOCKED: brake on, press 'n'`).
2. **P-sv turned to maximum** — the SYS manual's own advice for *"when the motor
   cannot adjust the speed"*.
3. **SV PWM moved 5 kHz → 2 kHz** — 5 kHz was outside the SYS manual's 1–3 kHz range.

Note (1) alone does **not** explain the first failure: `bench_20260805_211945.csv`
shows `EN:on BRK:off duty 4095 ~3.30 V` held 16 s with no movement and the
interlocks all clear. So (2) or (3) — or both — mattered.

**To find out:** with the rig running, set PWM back to 5 kHz and see if it stops;
then restore 2 kHz and back P-sv off. Cheap now, expensive to guess later.

### Working key sequence

```
n  brake off  →  f  forward  →  e  enable  →  3  30% duty
```

---

## 2. Hardware setup

```
ESP32-S3-DevKitC ── adapter (perfboard) ── BLD-120A ── BLDC motor (15:1, 150 mm wheel)
                                              24 V bench PSU
```

### Bench pin map — **NOT the PCB pinout**

| Signal | GPIO | Via |
|---|---|---|
| SV | **4** | 1.5 kΩ series |
| EN | **8** | transistor |
| BRK | **9** | transistor |
| F/R | **15** | transistor |
| COM | GND | plain wire |

> On the fabricated Wheel Drive PCB, **GPIO8/9 are I²C SDA/SCL and GPIO4 is a ToF
> XSHUT line.** The FL wheel there is SV=42, F/R=41, EN=40, BRK=39. See
> `include/pins.h`, which is generated from the netlist. Do not carry the bench
> wiring over.

### Adapter, per control line

```
GPIO ──10 kΩ──┬── Base          Collector → driver input
              │                 Emitter   → COM
           100 kΩ
              │
             COM               SV: 1.5 kΩ series, no transistor
```

**The transistor inverts.** GPIO HIGH = transistor on = driver input pulled to
COM = **asserted**. Firmware handles this via `fal::kControlViaMosfet = true` in
`lib/hal_esp32/Bld120aMotor.h`; `bench_s3_motor.cpp` has the same constants inline.

---

## 3. Facts already established — do NOT re-derive these

Each cost real time to pin down. Sources in `docs/hardware-architecture.md`.

| Fact | Evidence |
|---|---|
| **SV is a high-impedance voltage input** | diode test 2026-08-05 read `OL` both directions. It does *not* load the source. |
| **The driver accepts PWM natively, 1–10 kHz** | manual, Speed Command mode C. No DAC / op-amp / RC filter needed. 20 kHz is out of spec. |
| **EN/BRK/F-R are optocouplers idling ~5 V** | internal pull-up ≈10 kΩ, ≈440 µA when pulled to COM. ESP32-S3 is not 5 V tolerant. |
| **A pulldown cannot replace the transistor** | pin-safe needs R ≤ 19.4 kΩ, opto-off needs R ≥ 32 kΩ. No overlap. |
| **RV pot must be fully ANTICLOCKWISE** | manual states it 3× — external speed control *fails* otherwise. |
| **P-sv is the overload power limit (30–120 W), not a speed trim** | manual §Settings. Wrong value trips the red LED and the motor won't run. |
| **There is no ALM terminal** | control block is only SV/COM/F-R/EN/BRK. "RUN/ALM" is an LED. |
| **The 2.59 V figure is stale** | 2026-07-15, ESP32 **DAC** on the WROOM-32D. Not applicable to the S3. |
| **`pins.h` is now netlist-derived** | the old map was pre-PCB intent and did not match the fabricated board. |

---

## 4. Test procedure
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

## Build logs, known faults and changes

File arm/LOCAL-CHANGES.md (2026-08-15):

# Local changes to `sks0826/Arm_code`

Everything here differs from upstream commit `ca81eef`. Three changes, all in
service of the base being able to drive this firmware over ESP-NOW.

**None of it has been upstreamed.** If Kai Xiang or Heng Li merge these, re-vendor
from their commit and delete this file rather than keeping two copies in step.
`docs/arm-espnow-jog.patch` is the same diff in applicable form.

---

## 1. `mstop` above the busy check — `src/main.cpp`

```cpp
  if (command == "estop") { emergencyStopEverything(true); return; }
+ if (command == "mstop") { stopTravelMotors(); ... sendWirelessStatus("stopped"); return; }

  if (isBusyForWirelessCommand()) { sendWirelessStatus("busy"); return; }
```

A running jog sets `xJog.active` / `yJog.active`, which makes
`isBusyForWirelessCommand()` true. A stop arriving from the remote would
therefore be answered `busy` and refused, and the jog would run its full 3 s
timeout regardless — silently turning a held-to-move control into a fixed burst.

`estop` was already hoisted for the same reason. `mstop` needs it for the same
reason.

## 2. Unknown wireless commands fall through to the serial handler

```cpp
  } else {
-   sendWirelessStatus("rejected:unknown_command");
+   processCommand(command);
  }
```

`processCommand()` already implements the manual jogs (`xext`/`xret`/`yext`/
`yret`), the per-axis flips (`fx`/`fy`/`ex`/`ey`) and everything else this
firmware can do. They were unreachable from the radio only because the two
handlers are separate functions — the logic existed, the door didn't.

One line exposes the lot, and the next command added to the serial set works
remotely for free instead of needing a matching string compare.

**It does mean `clamp`, `limit` and the raw servo sweeps are now reachable over
the air.** Fine between two paired boards on a bench. Reconsider if this ever
runs somewhere a stray packet would matter — the receiver already filters on
sender MAC, so the exposure is bounded by that.

## 3. The servo flip cache is invalidated when we lose control

`src/MotorController.{h,cpp}` — added `flipStateKnown_`.

`xAxisFlipped_` / `yAxisFlipped_` record what was last **commanded**, and the
setters skip the move when the request already matches:

```cpp
  if (yAxisFlipped_ == flipped) {
    return true;            // reports SUCCESS without moving
  }
```

That is a useful shortcut until the servos stop obeying. `stopAll()` cuts PWM on
all four channels and an aborted ramp leaves them part-way; neither reset the
flags. So after any E-stop the cache still claimed a position the arms were no
longer holding, the next flip saw its request already satisfied, returned success
without moving, and the cycle went straight to retract.

Observed on hardware 2026-08-14 as *"the Y flippers didn't come up after
extending, but it still retracted when the limit switch was hit."* The retract
worked because nothing was wrong with the retract.

Reachable without an E-stop too: flip a pair by hand, then run `grab`, and grab's
flip is skipped.

Fixed with a **validity flag** rather than by resetting the position — resetting
has to pick a value, and either choice is wrong half the time. Claiming "home"
after PWM is cut just moves the silent no-op onto the next *home* command
instead. The cache is now used only when it is both matching **and** known good:
`stopAll()` clears it, `begin()` sets it after driving all four to home, and a
completed ramp sets it.

---

## Known upstream issues NOT fixed here

These are real and were left alone because they are the authors' to decide on.
Both are described in full in [`../docs/gotchas.md`](../docs/gotchas.md).

- **An out-of-range ToF reading counts as "clear air."** `TOF_OUT_OF_RANGE_MM`
  is 8191 and the air test is `> 200`, so a disconnected, failed or
  pointed-at-nothing sensor reports the exact condition that lets the arm stop
  extending. The sensor's failure mode is indistinguishable from its all-clear.
- **Extend trusts one limit switch; retract trusts three.** `isXExtendBlocked`
  reads `X_ARM_MAX` (GPIO42) alone, while `isXRetractBlocked` reads
  `X_ARM_MIN` ∥ `LIMIT_X1` ∥ `LIMIT_X2`. Extend has no redundancy, and a working
  retract stop tells you nothing about whether extend has one.

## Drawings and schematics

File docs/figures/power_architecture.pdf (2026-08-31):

## Power Distribution System Architecture

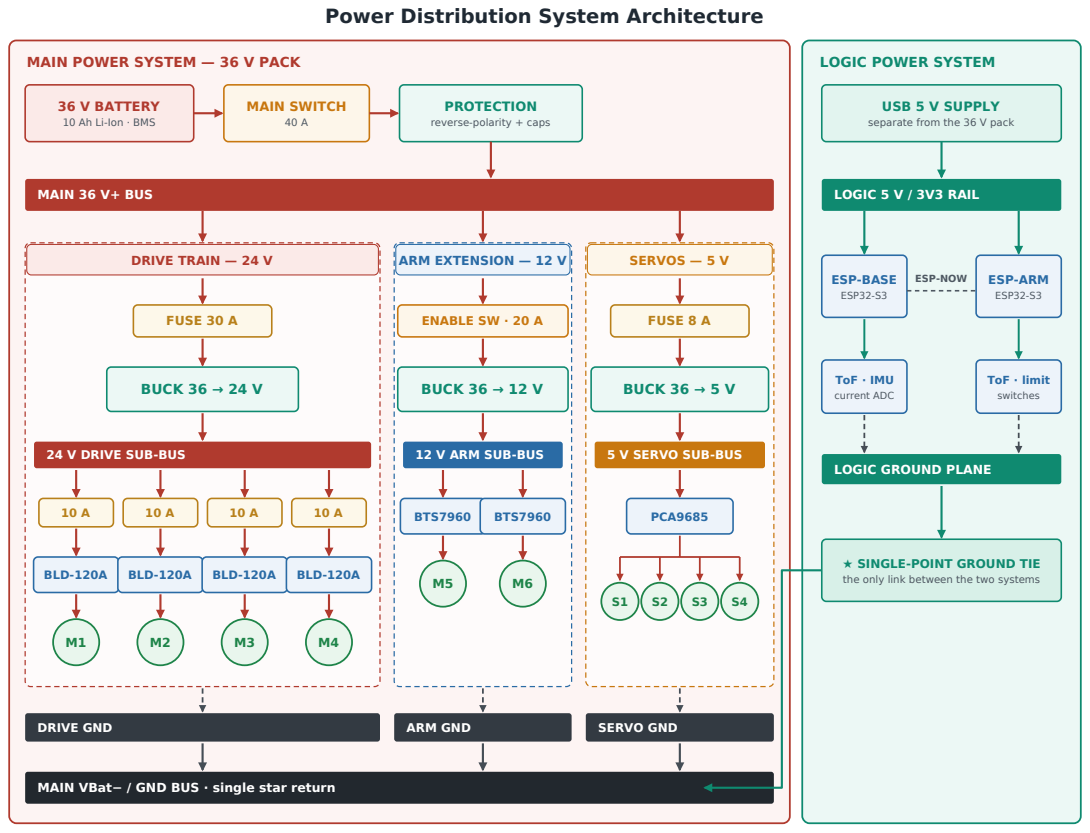
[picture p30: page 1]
MAIN POWER SYSTEM — 36 V PACK; LOGIC POWER SYSTEM; MAIN SWITCH 40 A; MAIN 36 V+ BUS; DRIVE TRAIN — 24 V; ARM EXTENSION — 12 V; SERVOS — 5 V; FUSE 30 A; BUCK 36 → 24 V; BLD-120A; ENABLE SW · 20 A; BUCK 36 → 12 V; BTS7960; FUSE 8 A; BUCK 36 → 5 V; PCA9685; DRIVE GND; ARM GND; SERVO GND; LOGIC 5 V / 3V3 RAIL; ESP-BASE; ESP32-S3; ESP-ARM; ESP-NOW; ToF · IMU current ADC; ToF · limit switches

36 V BATTERY
10 Ah Li-Ion · BMS

PROTECTION
reverse-polarity + caps

USB 5 V SUPPLY
separate from the 36 V pack

24 V DRIVE SUB-BUS

12 V ARM SUB-BUS

5 V SERVO SUB-BUS

LOGIC GROUND PLANE

★ SINGLE-POINT GROUND TIE
the only link between the two systems

MAIN VBat− / GND BUS · single star return

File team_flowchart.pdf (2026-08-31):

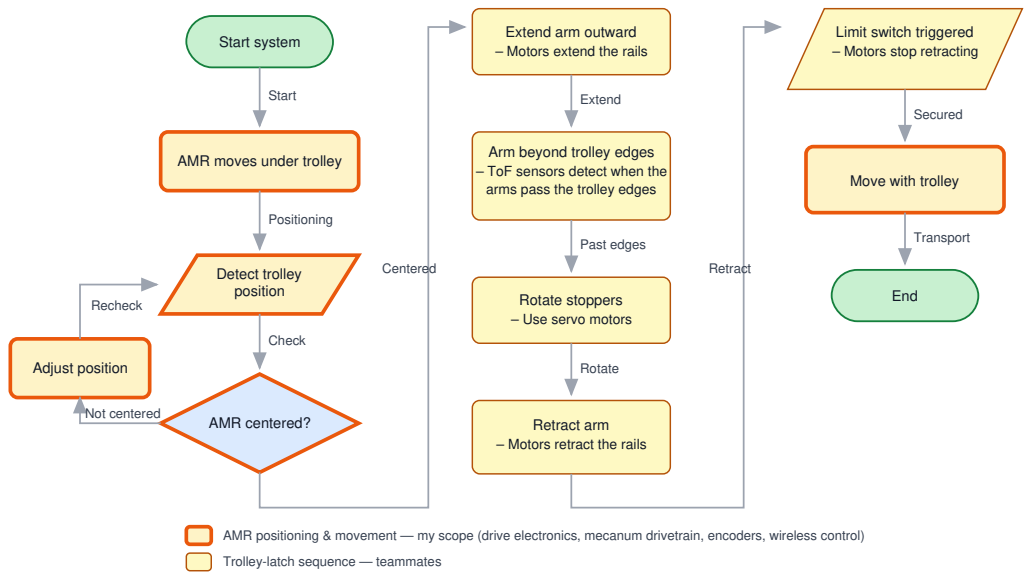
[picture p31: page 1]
Start system; Start; Positioning; Detect trolley position; Check; AMR centered?; Adjust position; Not centered; Recheck; Centered; Extend; Past edges; Rotate; Retract; Secured; Transport; End

Extend arm outward
– Motors extend the rails

Limit switch triggered
– Motors stop retracting

Arm beyond trolley edges
– ToF sensors detect when the
arms pass the trolley edges

AMR moves under trolley

Move with trolley

Rotate stoppers
– Use servo motors

Retract arm
– Motors retract the rails

AMR positioning & movement — my scope (drive electronics, mecanum drivetrain, encoders, wireless control)

Trolley-latch sequence — teammates

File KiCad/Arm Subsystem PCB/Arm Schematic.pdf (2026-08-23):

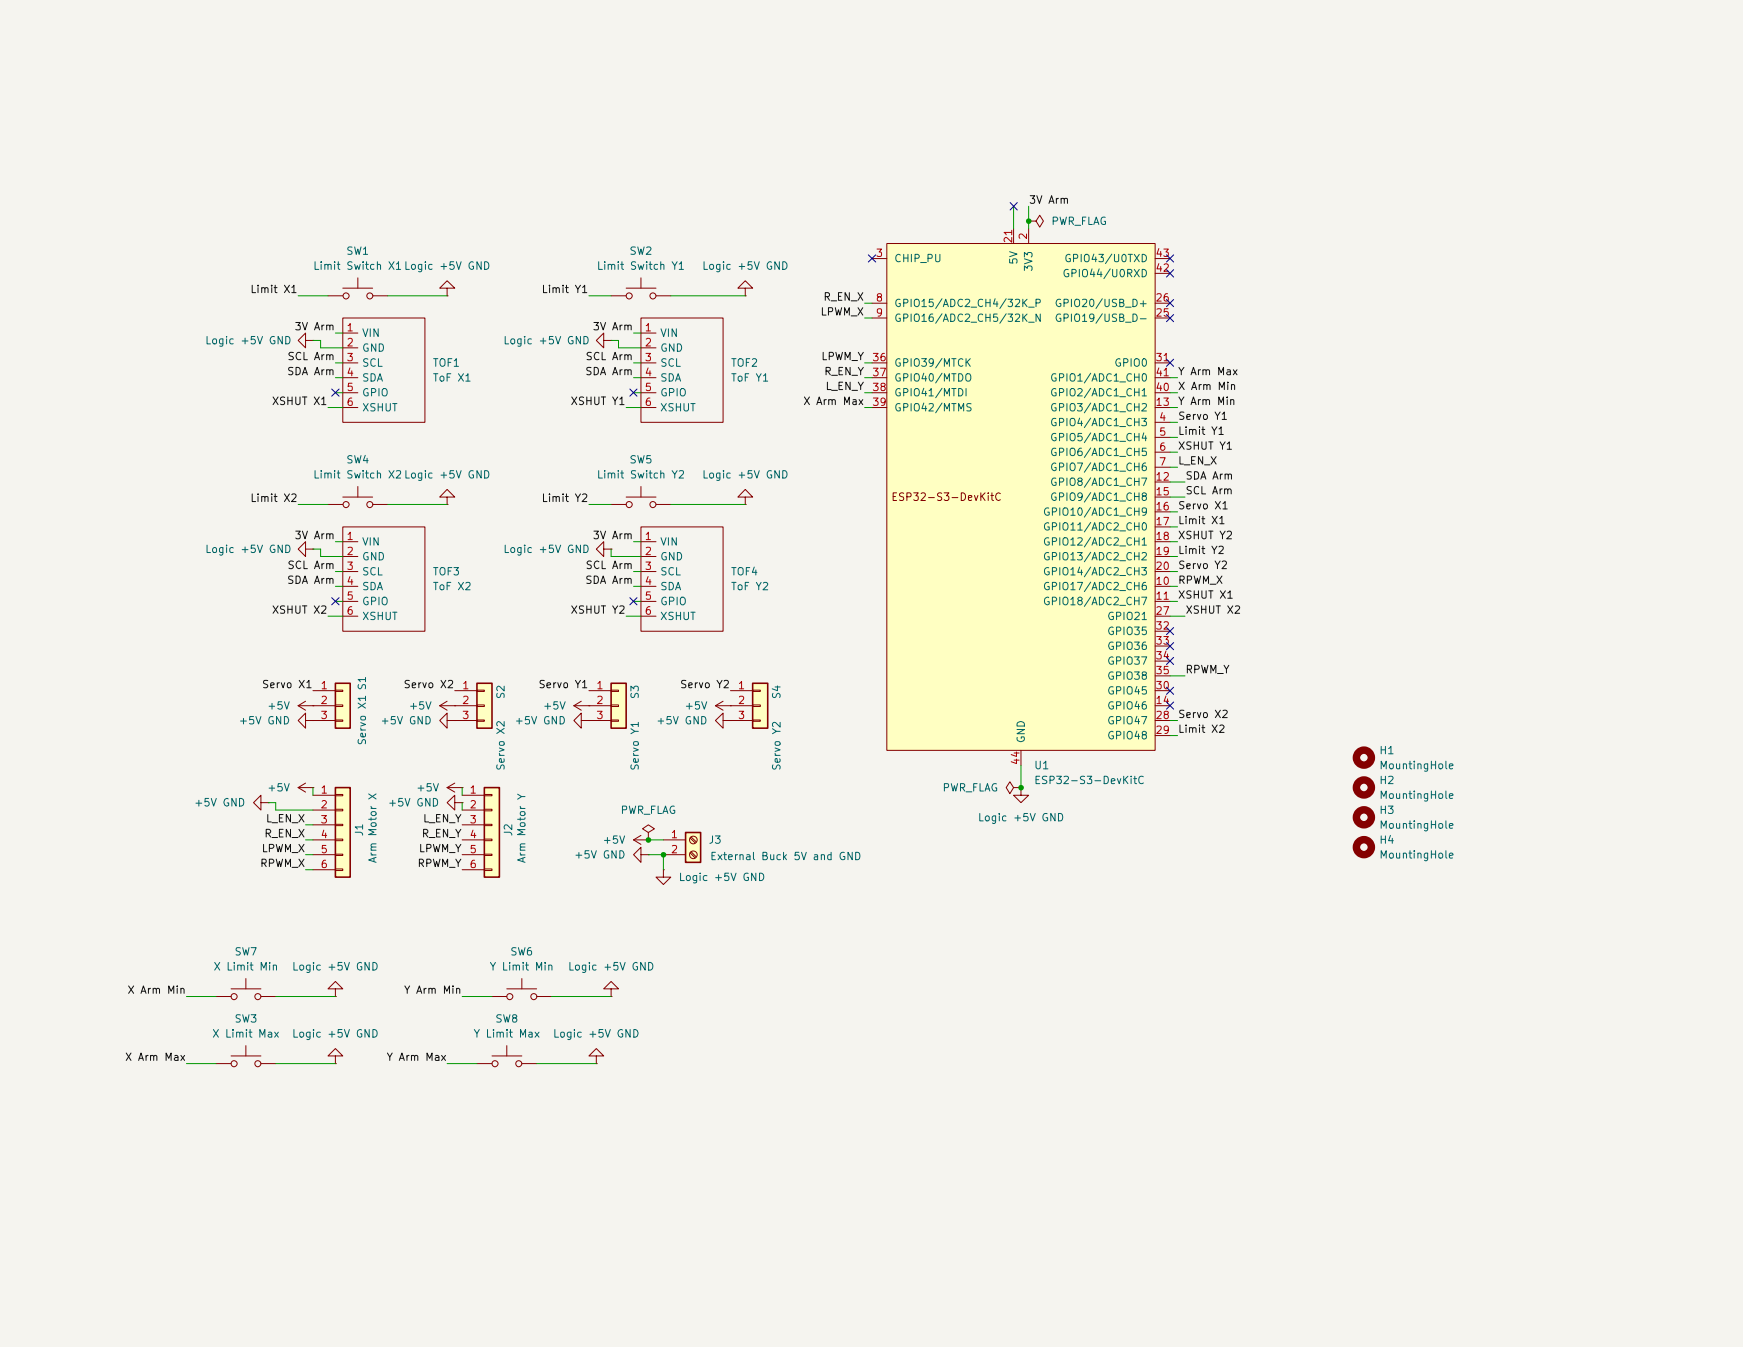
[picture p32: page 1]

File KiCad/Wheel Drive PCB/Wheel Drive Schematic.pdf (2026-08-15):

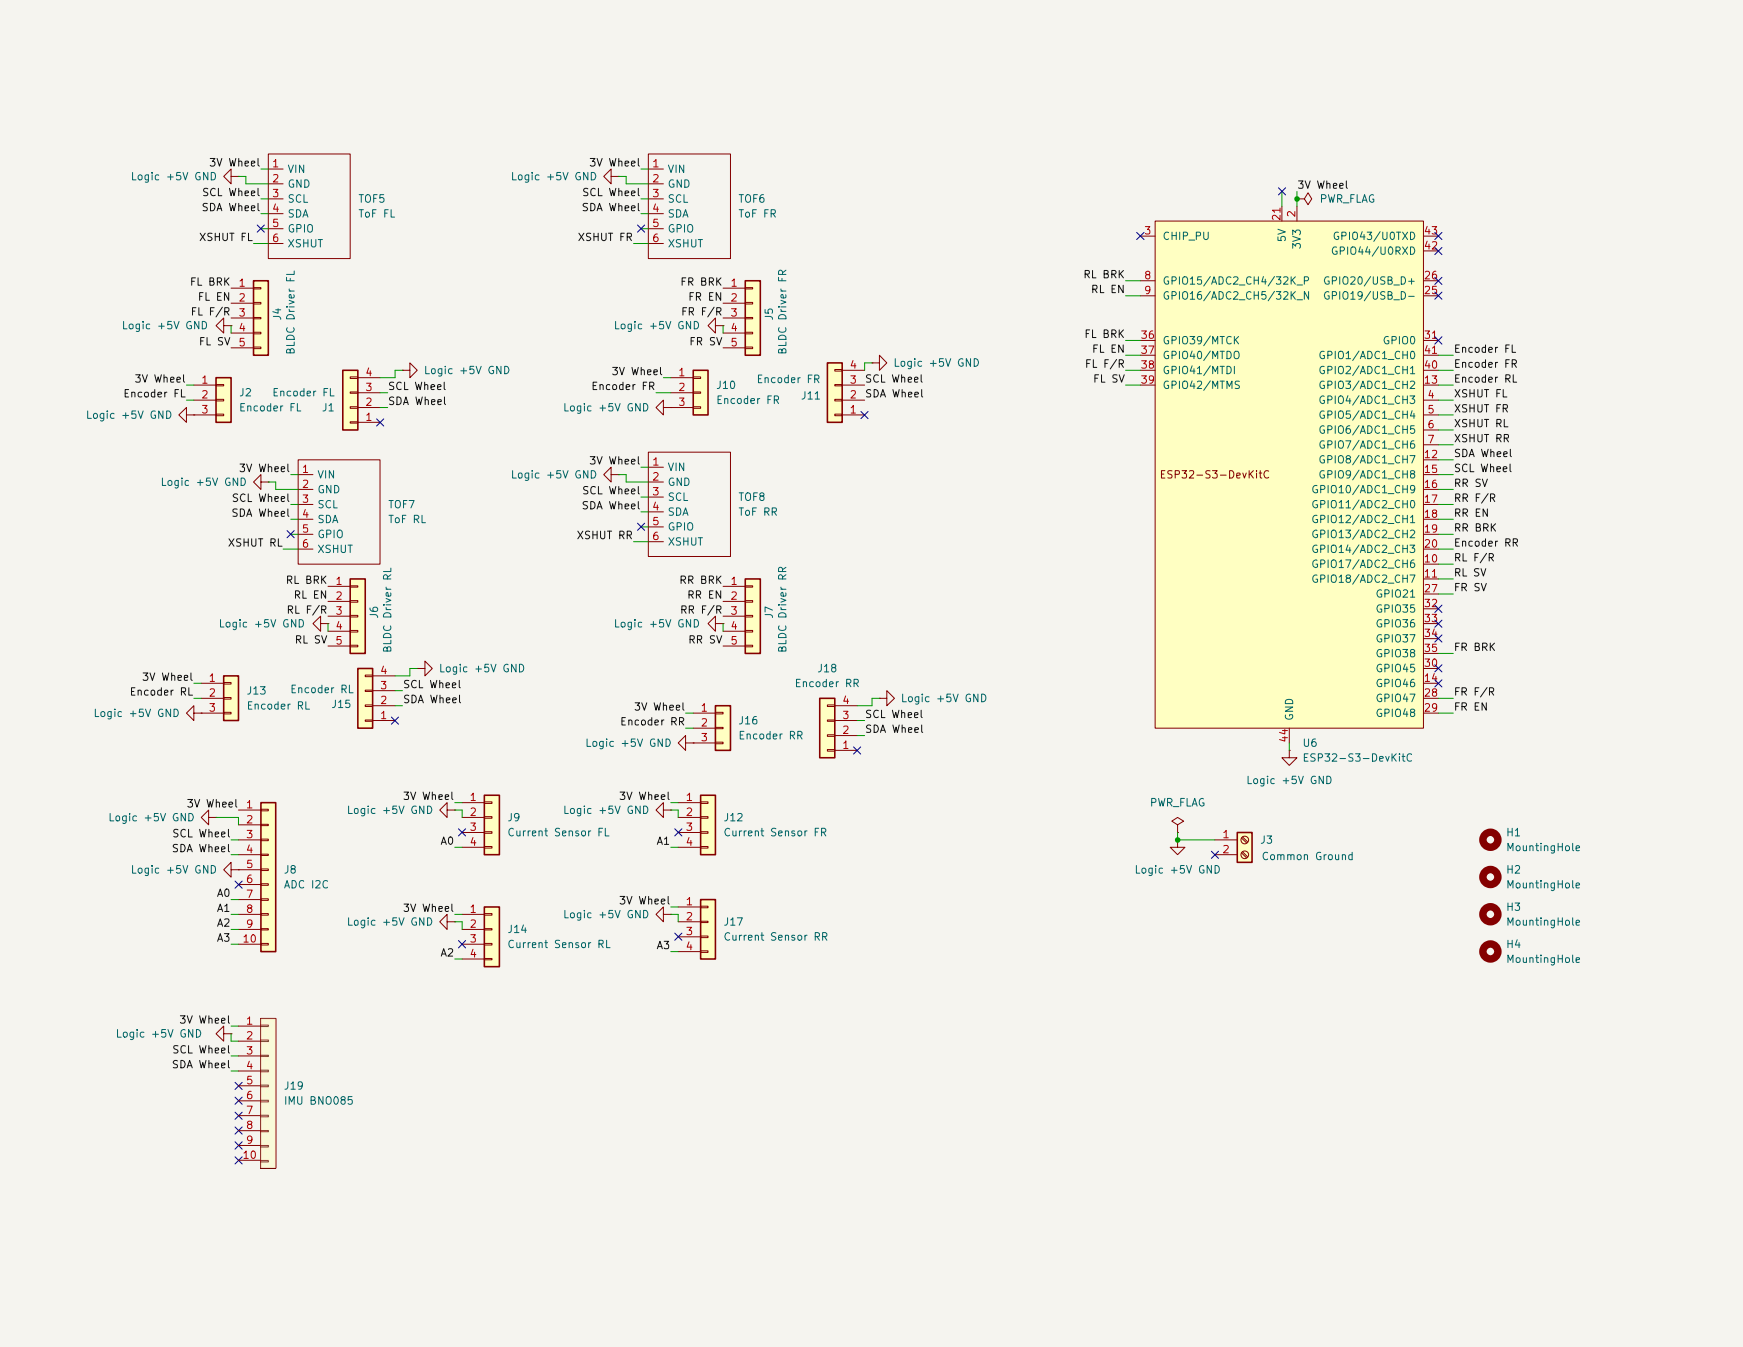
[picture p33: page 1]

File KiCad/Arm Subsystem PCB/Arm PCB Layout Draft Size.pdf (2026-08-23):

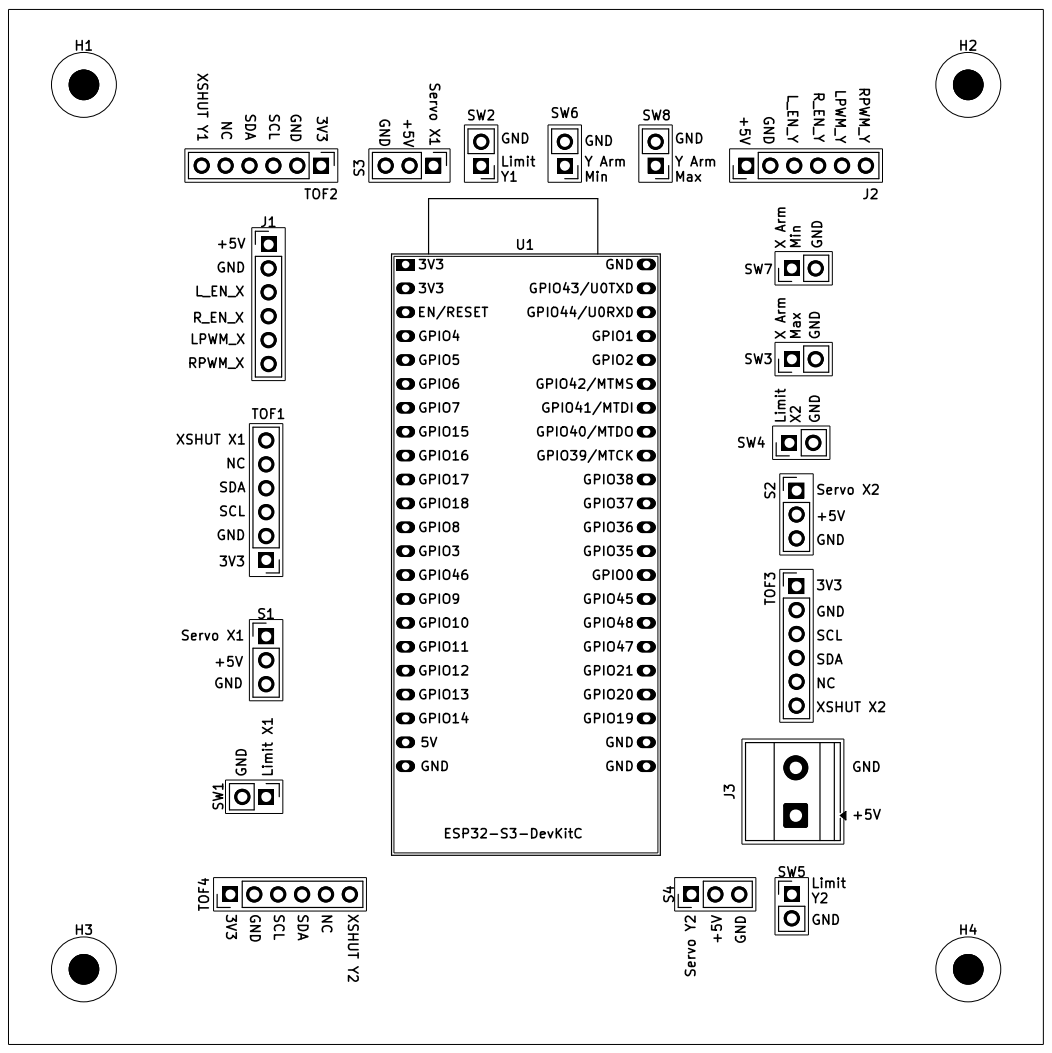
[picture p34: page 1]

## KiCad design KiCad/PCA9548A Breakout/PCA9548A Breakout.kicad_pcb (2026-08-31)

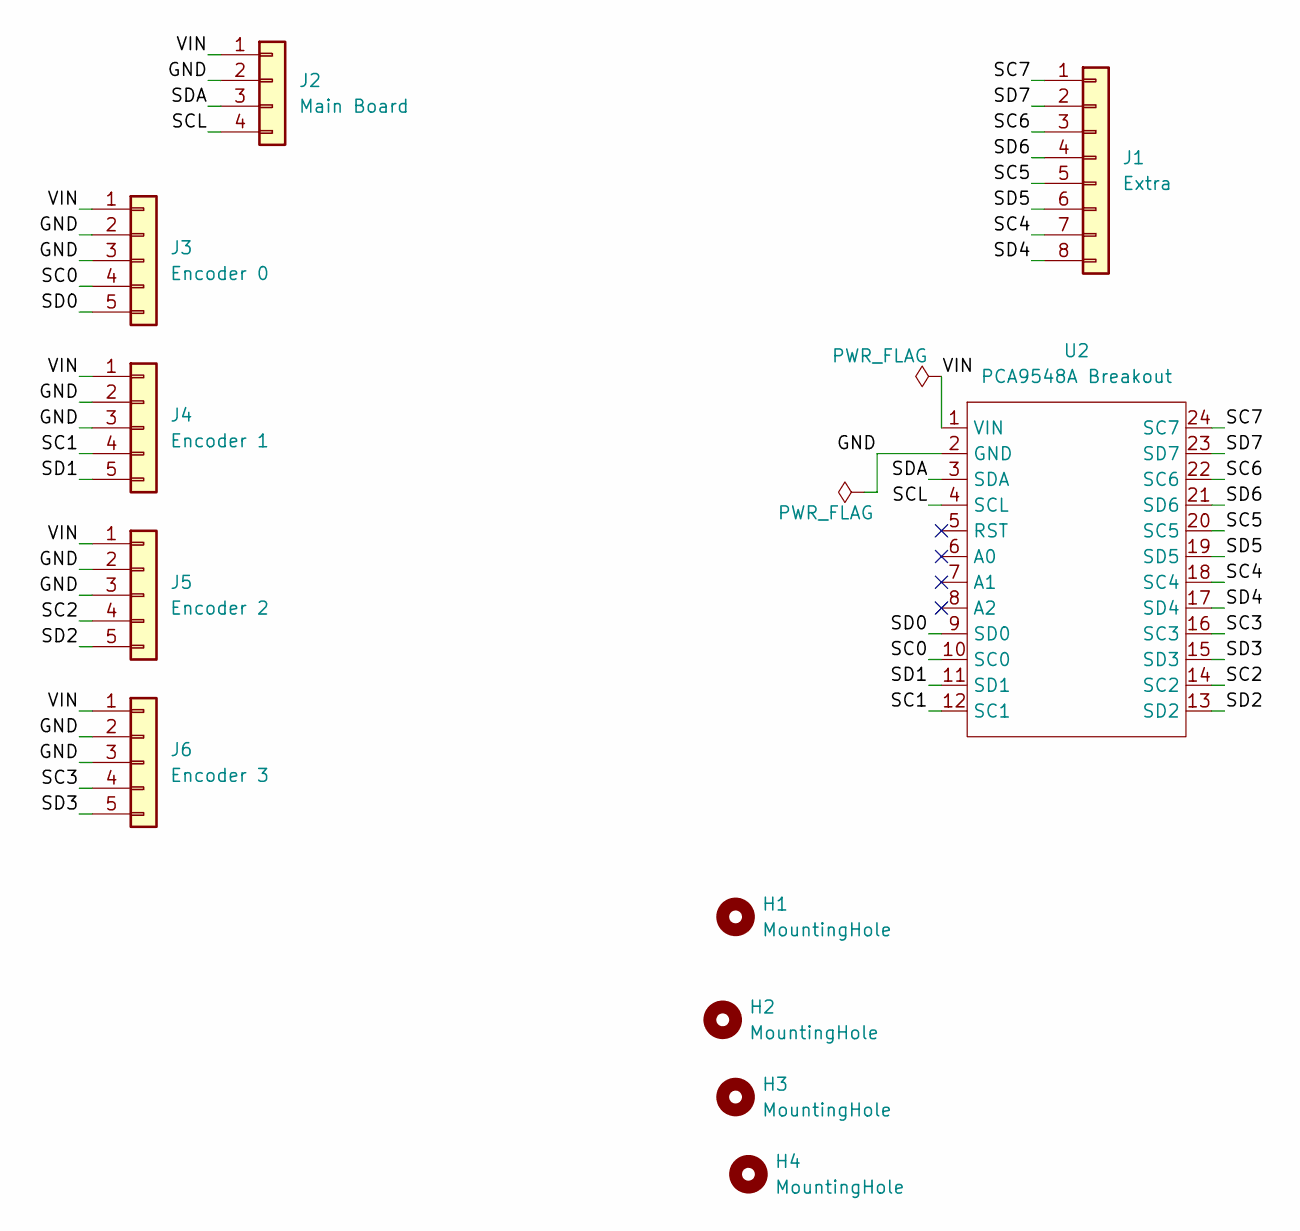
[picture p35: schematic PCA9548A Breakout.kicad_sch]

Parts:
H1, H2, H3, H4: MountingHole; MountingHole_3.2mm_M3
J1: Extra; PinHeader_1x08_P2.54mm_Vertical
J2: Main Board; PinHeader_1x04_P2.54mm_Vertical
J3: Encoder 0; PinHeader_1x05_P2.54mm_Vertical
J4: Encoder 1; PinHeader_1x05_P2.54mm_Vertical
J5: Encoder 2; PinHeader_1x05_P2.54mm_Vertical
J6: Encoder 3; PinHeader_1x05_P2.54mm_Vertical
U2: PCA9548A Breakout

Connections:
/GND: J2.2, J3.2, J3.3, J4.2, J4.3, J5.2, J5.3, J6.2, J6.3, U2.2 (GND)
/SC0: J3.4, U2.10 (SC0)
/SC1: J4.4, U2.12 (SC1)
/SC2: J5.4, U2.14 (SC2)
/SC3: J6.4, U2.16 (SC3)
/SC4: J1.7, U2.18 (SC4)
/SC5: J1.5, U2.20 (SC5)
/SC6: J1.3, U2.22 (SC6)
/SC7: J1.1, U2.24 (SC7)
/SCL: J2.4, U2.4 (SCL)
/SD0: J3.5, U2.9 (SD0)
/SD1: J4.5, U2.11 (SD1)
/SD2: J5.5, U2.13 (SD2)
/SD3: J6.5, U2.15 (SD3)
/SD4: J1.8, U2.17 (SD4)
/SD5: J1.6, U2.19 (SD5)
/SD6: J1.4, U2.21 (SD6)
/SD7: J1.2, U2.23 (SD7)
/SDA: J2.3, U2.3 (SDA)
/VIN: J2.1, J3.1, J4.1, J5.1, J6.1, U2.1 (VIN)

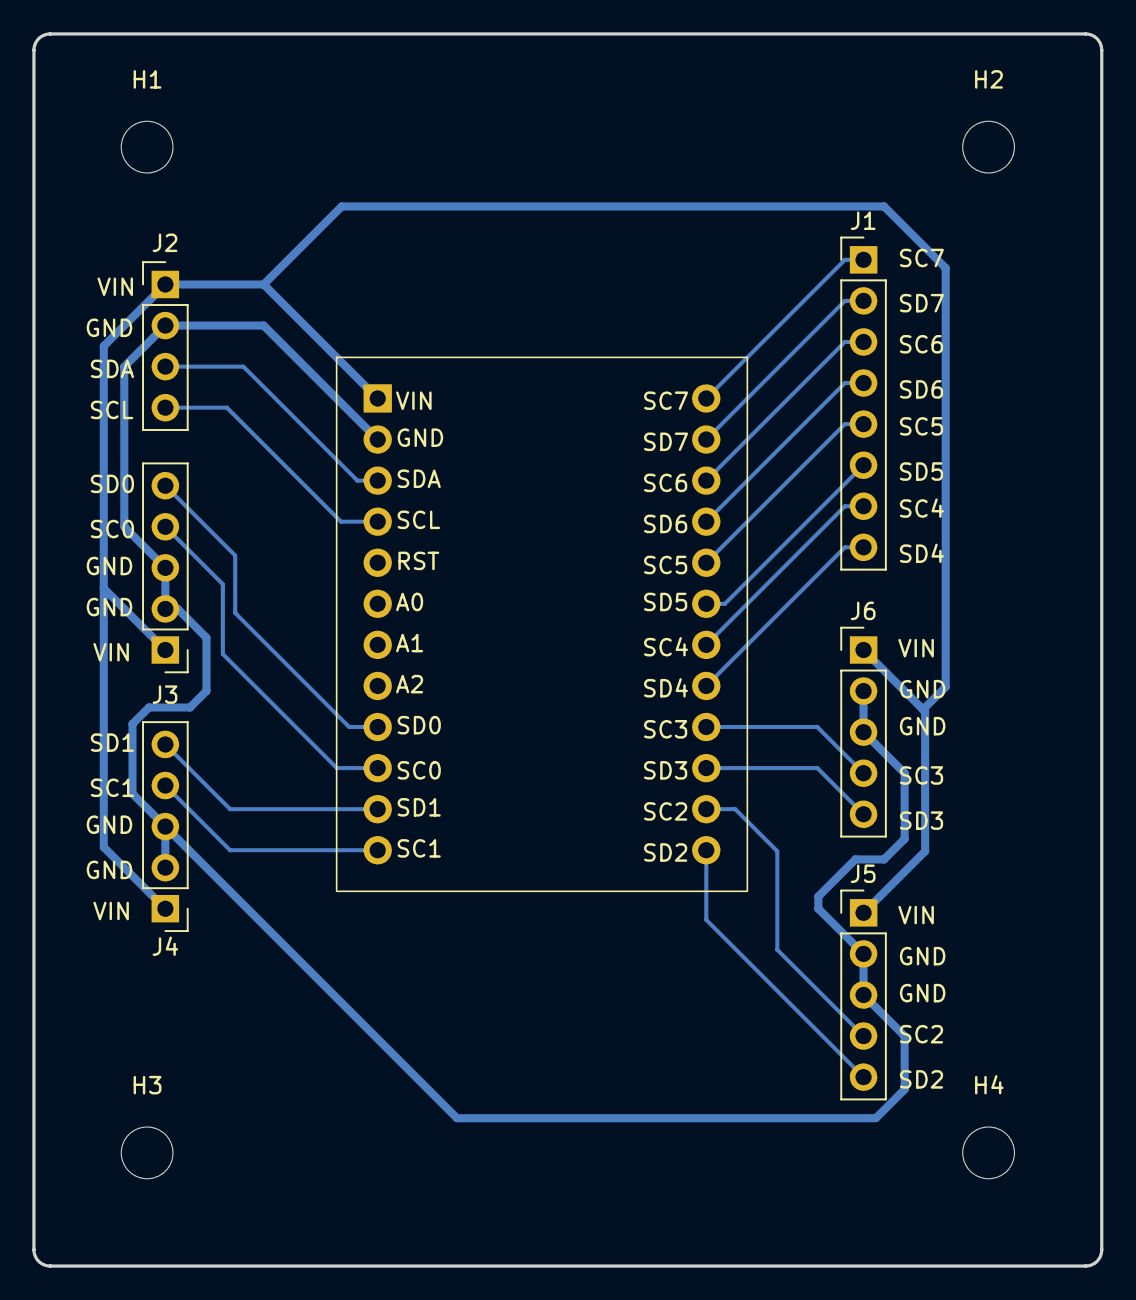
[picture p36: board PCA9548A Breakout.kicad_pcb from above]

Board: 2 copper layers, 66.0 x 76.2 mm, 11 parts (0 on the bottom side), 20 nets.

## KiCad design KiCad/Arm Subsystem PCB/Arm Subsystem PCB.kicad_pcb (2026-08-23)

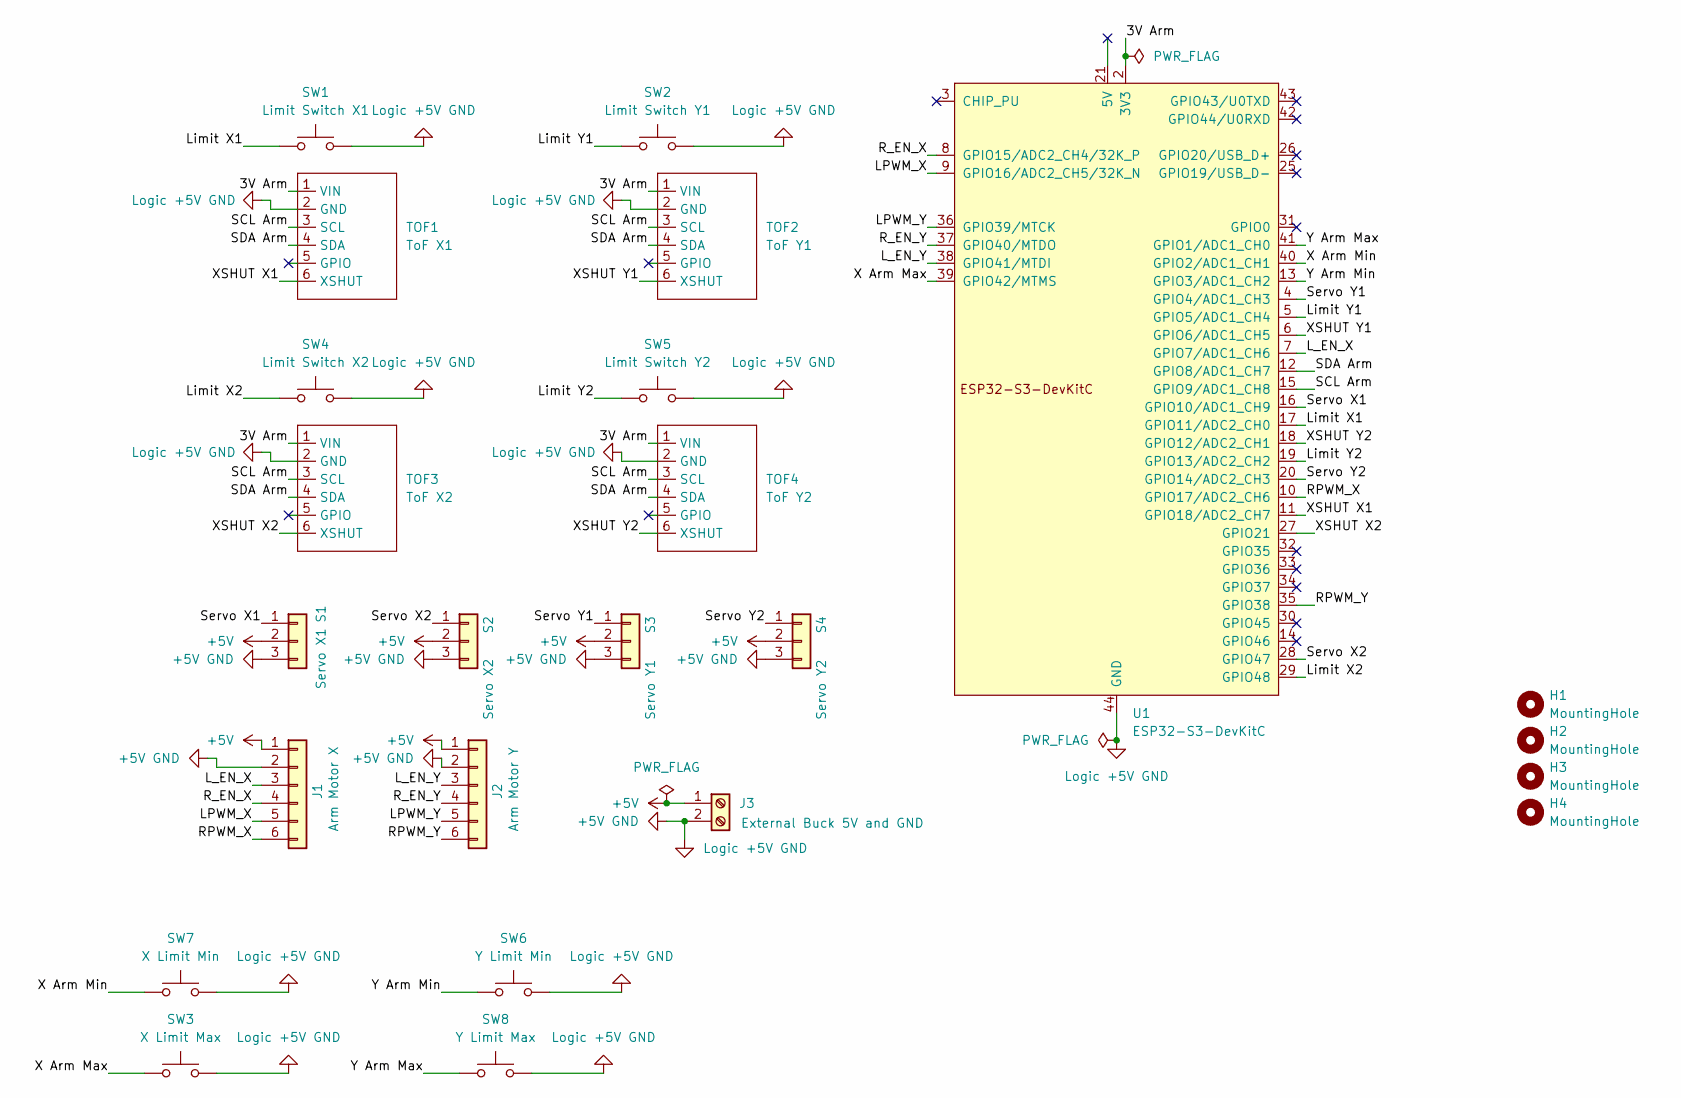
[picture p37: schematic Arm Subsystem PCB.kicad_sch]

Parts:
H1, H2, H3, H4: MountingHole; MountingHole_3.2mm_M3
J1: Arm Motor X; PinHeader_1x06_P2.54mm_Vertical
J2: Arm Motor Y; PinHeader_1x06_P2.54mm_Vertical
J3: External Buck 5V and GND; TerminalBlock_Phoenix_MKDS-1,5-2-5.08_1x02_P5.08mm_Horizont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
S1: Servo X1; PinHeader_1x03_P2.54mm_Vertical
S2: Servo X2; PinHeader_1x03_P2.54mm_Vertical
S3: Servo Y1; PinHeader_1x03_P2.54mm_Vertical
S4: Servo Y2; PinHeader_1x03_P2.54mm_Vertical
SW1: Limit Switch X1; PinHeader_1x02_P2.54mm_Vertical
SW2: Limit Switch Y1; PinHeader_1x02_P2.54mm_Vertical
SW3: X Limit Max; PinHeader_1x02_P2.54mm_Vertical
SW4: Limit Switch X2; PinHeader_1x02_P2.54mm_Vertical
SW5: Limit Switch Y2; PinHeader_1x02_P2.54mm_Vertical
SW6: Y Limit Min; PinHeader_1x02_P2.54mm_Vertical
SW7: X Limit Min; PinHeader_1x02_P2.54mm_Vertical
SW8: Y Limit Max; PinHeader_1x02_P2.54mm_Vertical
TOF1: ToF X1; PinHeader_1x06_P2.54mm_Vertical
TOF2: ToF Y1; PinHeader_1x06_P2.54mm_Vertical
TOF3: ToF X2; PinHeader_1x06_P2.54mm_Vertical
TOF4: ToF Y2; PinHeader_1x06_P2.54mm_Vertical
U1: ESP32-S3-DevKitC; ESP32-S3-DevKitC-N16R8

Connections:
+5V: J1.1, J2.1, J3.1, S1.2, S2.2, S3.2, S4.2
+5V GND: J1.2, J2.2, J3.2, S1.3, S2.3, S3.3, S4.3, SW1.2, SW2.2, SW3.2, SW4.2, SW5.2, SW6.2, SW7.2, SW8.2, TOF1.2 (GND), TOF2.2 (GND), TOF3.2 (GND), TOF4.2 (GND), U1.22 (GND), U1.23 (GND), U1.24 (GND), U1.44 (GND)
/3V Arm: TOF1.1 (VIN), TOF2.1 (VIN), TOF3.1 (VIN), TOF4.1 (VIN), U1.1 (3V3), U1.2 (3V3)
/LPWM_X: J1.5, U1.9 (GPIO16/ADC2_CH5/32K_N)
/LPWM_Y: J2.5, U1.36 (GPIO39/MTCK)
/L_EN_X: J1.3, U1.7 (GPIO7/ADC1_CH6)
/L_EN_Y: J2.3, U1.38 (GPIO41/MTDI)
/Limit X1: SW1.1, U1.17 (GPIO11/ADC2_CH0)
/Limit X2: SW4.1, U1.29 (GPIO48)
/Limit Y1: SW2.1, U1.5 (GPIO5/ADC1_CH4)
/Limit Y2: SW5.1, U1.19 (GPIO13/ADC2_CH2)
/RPWM_X: J1.6, U1.10 (GPIO17/ADC2_CH6)
/RPWM_Y: J2.6, U1.35 (GPIO38)
/R_EN_X: J1.4, U1.8 (GPIO15/ADC2_CH4/32K_P)
/R_EN_Y: J2.4, U1.37 (GPIO40/MTDO)
/SCL Arm: TOF1.3 (SCL), TOF2.3 (SCL), TOF3.3 (SCL), TOF4.3 (SCL), U1.15 (GPIO9/ADC1_CH8)
/SDA Arm: TOF1.4 (SDA), TOF2.4 (SDA), TOF3.4 (SDA), TOF4.4 (SDA), U1.12 (GPIO8/ADC1_CH7)
/Servo X1: S1.1, U1.16 (GPIO10/ADC1_CH9)
/Servo X2: S2.1, U1.28 (GPIO47)
/Servo Y1: S3.1, U1.4 (GPIO4/ADC1_CH3)
/Servo Y2: S4.1, U1.20 (GPIO14/ADC2_CH3)
/X Arm Max: SW3.1, U1.39 (GPIO42/MTMS)
/X Arm Min: SW7.1, U1.40 (GPIO2/ADC1_CH1)
/XSHUT X1: TOF1.6 (XSHUT), U1.11 (GPIO18/ADC2_CH7)
/XSHUT X2: TOF3.6 (XSHUT), U1.27 (GPIO21)
/XSHUT Y1: TOF2.6 (XSHUT), U1.6 (GPIO6/ADC1_CH5)
/XSHUT Y2: TOF4.6 (XSHUT), U1.18 (GPIO12/ADC2_CH1)
/Y Arm Max: SW8.1, U1.41 (GPIO1/ADC1_CH0)
/Y Arm Min: SW6.1, U1.13 (GPIO3/ADC1_CH2)

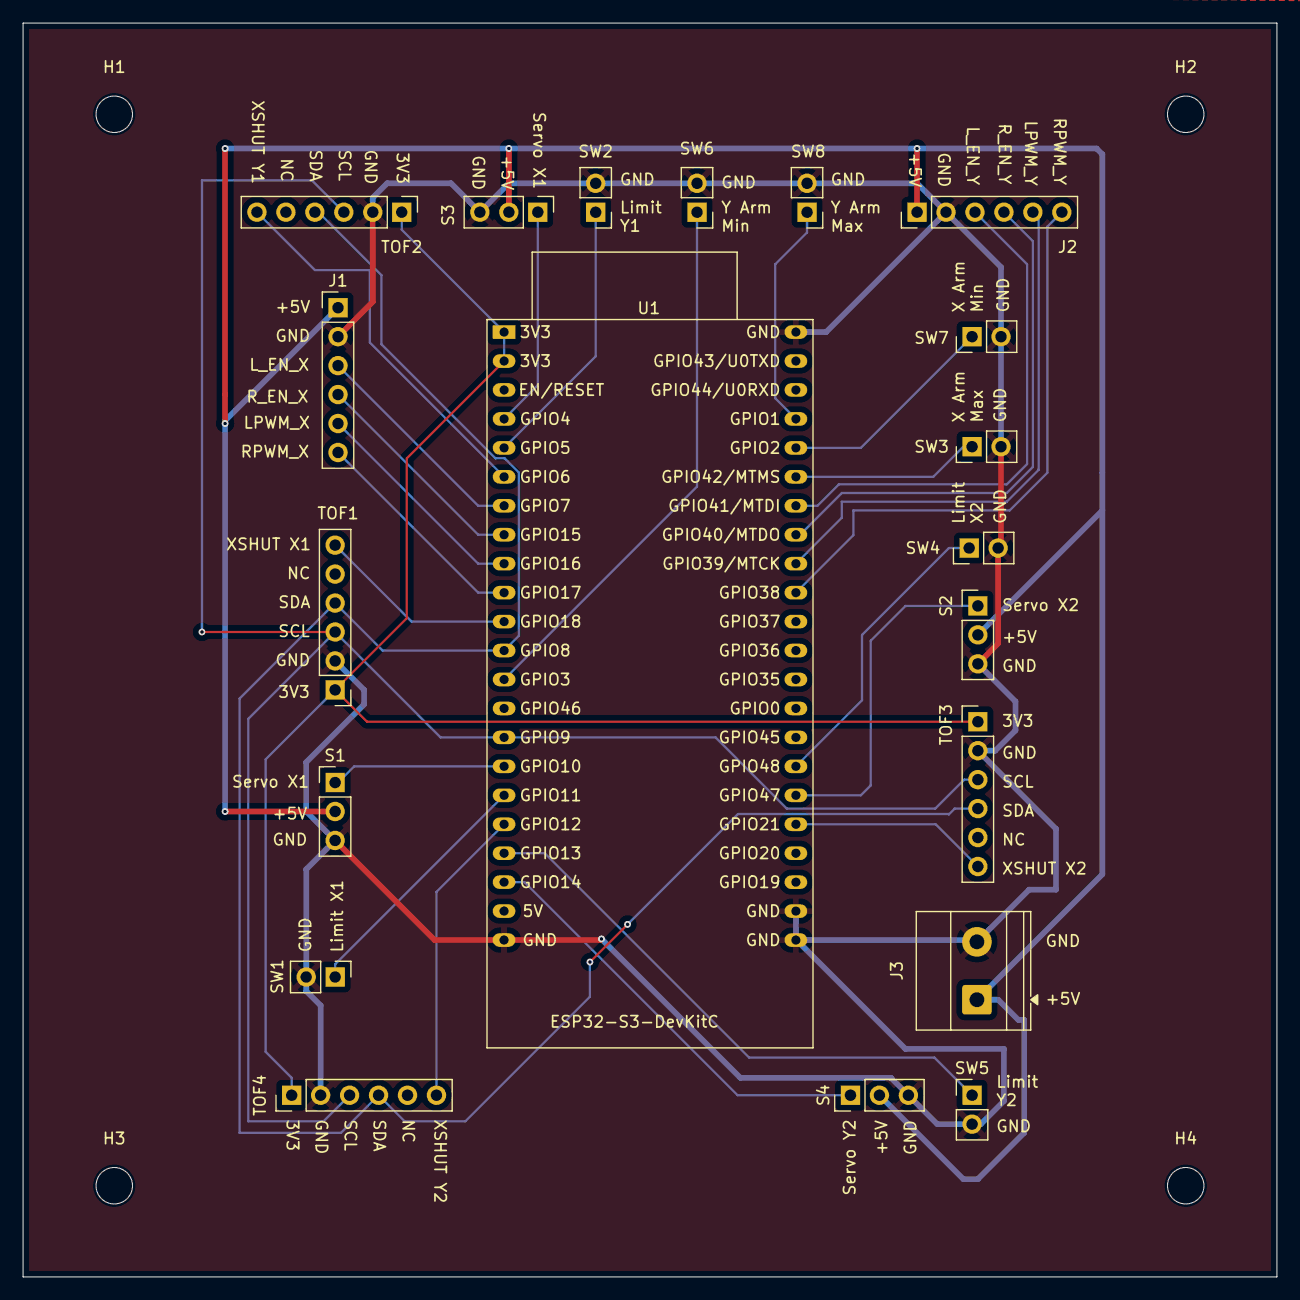
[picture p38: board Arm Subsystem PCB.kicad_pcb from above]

Board: 2 copper layers, 110.0 x 110.0 mm, 24 parts (0 on the bottom side), 29 nets.

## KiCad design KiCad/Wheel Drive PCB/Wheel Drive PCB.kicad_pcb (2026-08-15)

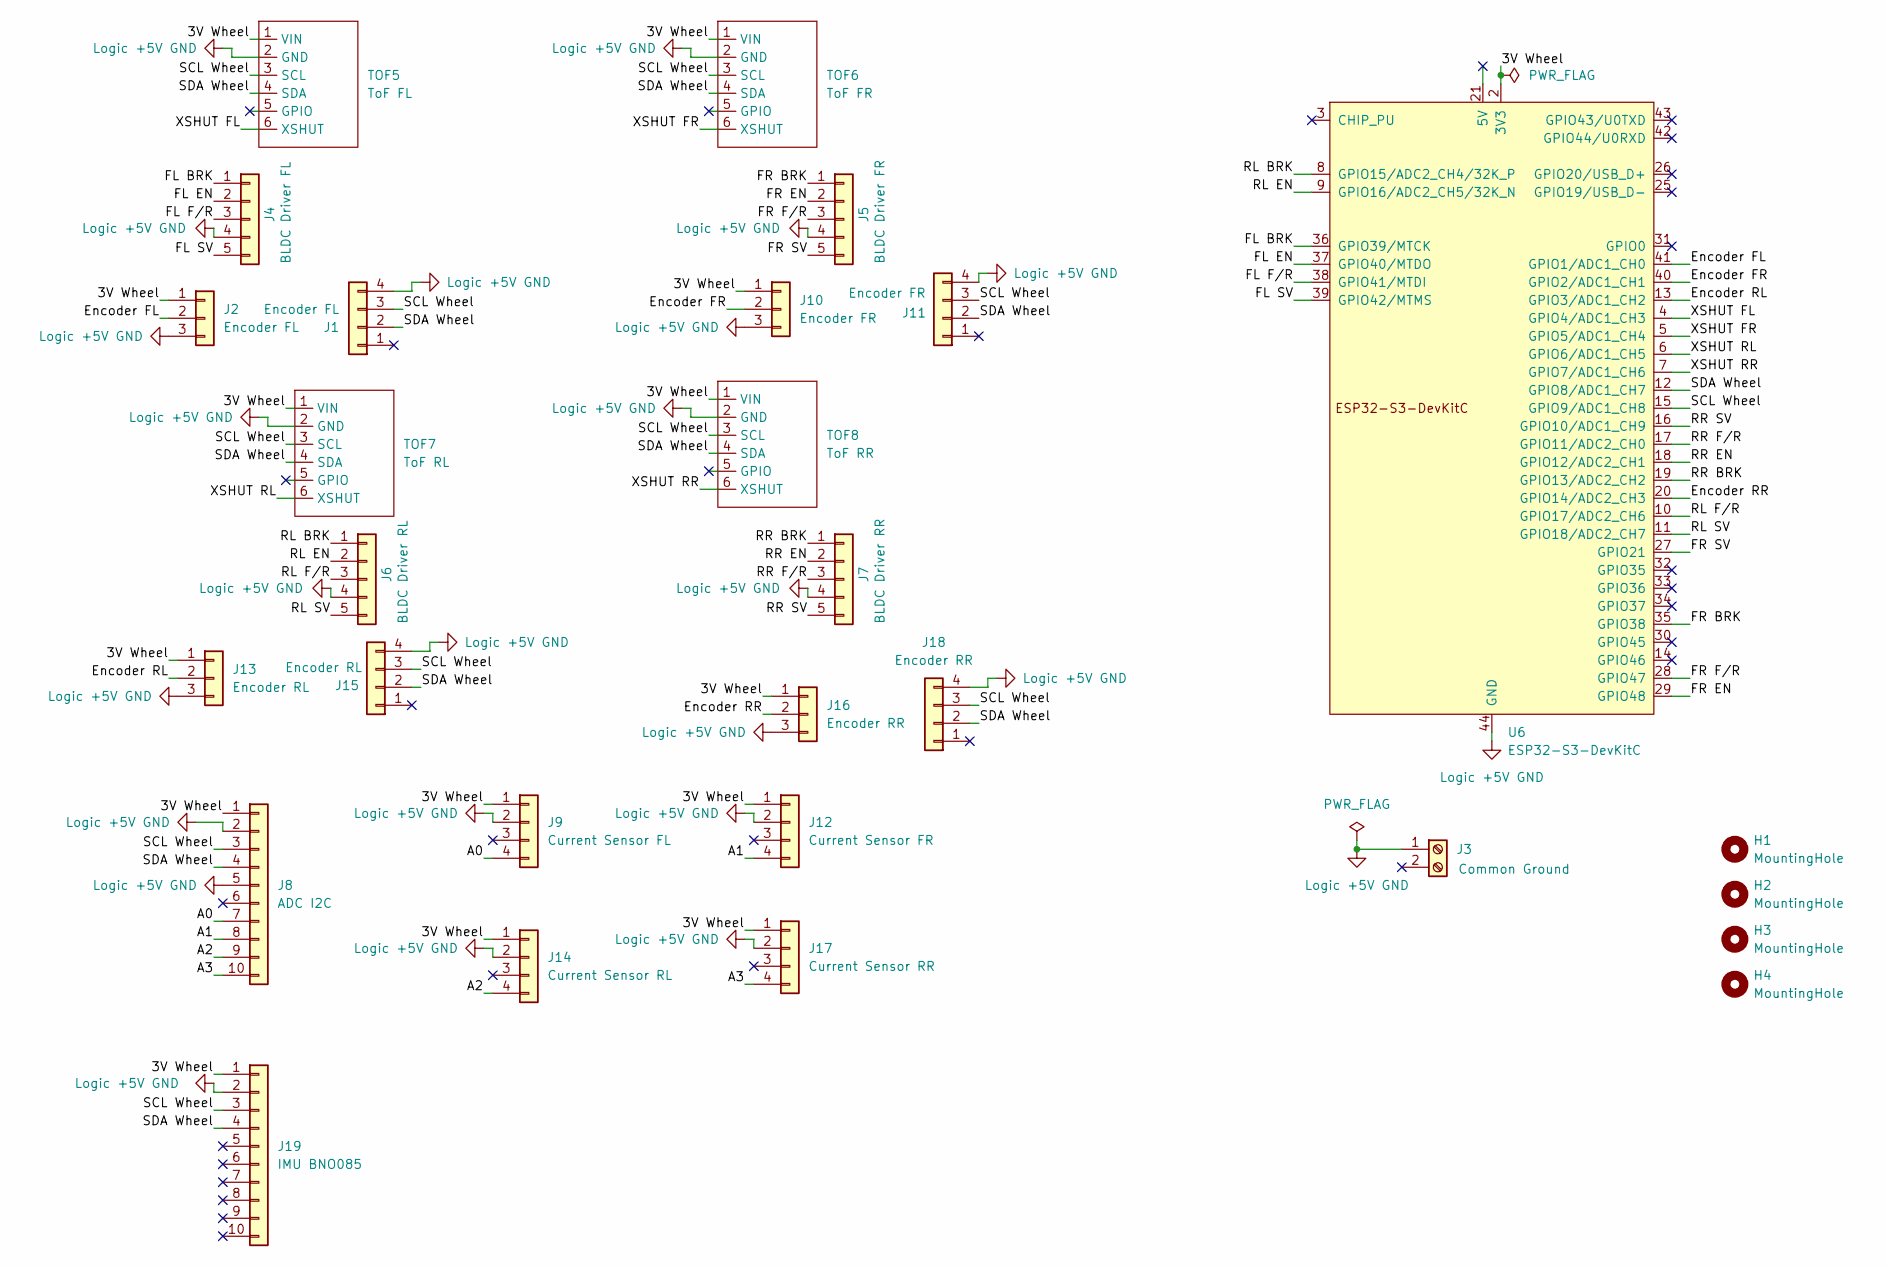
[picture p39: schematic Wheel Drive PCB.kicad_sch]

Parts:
H1, H2, H3, H4: MountingHole; MountingHole_3.2mm_M3
J1: Encoder FL; PinHeader_1x04_P2.54mm_Vertical
J2: Encoder FL; PinHeader_1x03_P2.54mm_Vertical
J3: Common Ground; TerminalBlock_Phoenix_MKDS-1,5-2-5.08_1x02_P5.08mm_Horizont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
J4: BLDC Driver FL; PinHeader_1x05_P2.54mm_Vertical
J5: BLDC Driver FR; PinHeader_1x05_P2.54mm_Vertical
J6: BLDC Driver RL; PinHeader_1x05_P2.54mm_Vertical
J7: BLDC Driver RR; PinHeader_1x05_P2.54mm_Vertical
J8: ADC I2C; PinHeader_1x10_P2.54mm_Vertical
J9: Current Sensor FL; PinHeader_1x04_P2.54mm_Vertical
J10: Encoder FR; PinHeader_1x03_P2.54mm_Vertical
J11: Encoder FR; PinHeader_1x04_P2.54mm_Vertical
J12: Current Sensor FR; PinHeader_1x04_P2.54mm_Vertical
J13: Encoder RL; PinHeader_1x03_P2.54mm_Vertical
J14: Current Sensor RL; PinHeader_1x04_P2.54mm_Vertical
J15: Encoder RL; PinHeader_1x04_P2.54mm_Vertical
J16: Encoder RR; PinHeader_1x03_P2.54mm_Vertical
J17: Current Sensor RR; PinHeader_1x04_P2.54mm_Vertical
J18: Encoder RR; PinHeader_1x04_P2.54mm_Vertical
J19: IMU BNO085; PinHeader_1x10_P2.54mm_Vertical
TOF5: ToF FL; PinHeader_1x06_P2.54mm_Vertical
TOF6: ToF FR; PinHeader_1x06_P2.54mm_Vertical
TOF7: ToF RL; PinHeader_1x06_P2.54mm_Vertical
TOF8: ToF RR; PinHeader_1x06_P2.54mm_Vertical
U6: ESP32-S3-DevKitC; ESP32-S3-DevKitC-N16R8

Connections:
/3V Wheel: J2.1, J8.1, J9.1, J10.1, J12.1, J13.1, J14.1, J16.1, J17.1, J19.1, TOF5.1 (VIN), TOF6.1 (VIN), TOF7.1 (VIN), TOF8.1 (VIN), U6.1 (3V3), U6.2 (3V3)
/A0: J8.7, J9.4
/A1: J8.8, J12.4
/A2: J8.9, J14.4
/A3: J8.10, J17.4
/Encoder FL: J2.2, U6.41 (GPIO1/ADC1_CH0)
/Encoder FR: J10.2, U6.40 (GPIO2/ADC1_CH1)
/Encoder RL: J13.2, U6.13 (GPIO3/ADC1_CH2)
/Encoder RR: J16.2, U6.20 (GPIO14/ADC2_CH3)
/FL BRK: J4.1, U6.36 (GPIO39/MTCK)
/FL EN: J4.2, U6.37 (GPIO40/MTDO)
/FL F/R: J4.3, U6.38 (GPIO41/MTDI)
/FL SV: J4.5, U6.39 (GPIO42/MTMS)
/FR BRK: J5.1, U6.35 (GPIO38)
/FR EN: J5.2, U6.29 (GPIO48)
/FR F/R: J5.3, U6.28 (GPIO47)
/FR SV: J5.5, U6.27 (GPIO21)
/RL BRK: J6.1, U6.8 (GPIO15/ADC2_CH4/32K_P)
/RL EN: J6.2, U6.9 (GPIO16/ADC2_CH5/32K_N)
/RL F/R: J6.3, U6.10 (GPIO17/ADC2_CH6)
/RL SV: J6.5, U6.11 (GPIO18/ADC2_CH7)
/RR BRK: J7.1, U6.19 (GPIO13/ADC2_CH2)
/RR EN: J7.2, U6.18 (GPIO12/ADC2_CH1)
/RR F/R: J7.3, U6.17 (GPIO11/ADC2_CH0)
/RR SV: J7.5, U6.16 (GPIO10/ADC1_CH9)
/SCL Wheel: J1.3, J8.3, J11.3, J15.3, J18.3, J19.3, TOF5.3 (SCL), TOF6.3 (SCL), TOF7.3 (SCL), TOF8.3 (SCL), U6.15 (GPIO9/ADC1_CH8)
/SDA Wheel: J1.2, J8.4, J11.2, J15.2, J18.2, J19.4, TOF5.4 (SDA), TOF6.4 (SDA), TOF7.4 (SDA), TOF8.4 (SDA), U6.12 (GPIO8/ADC1_CH7)
/XSHUT FL: TOF5.6 (XSHUT), U6.4 (GPIO4/ADC1_CH3)
/XSHUT FR: TOF6.6 (XSHUT), U6.5 (GPIO5/ADC1_CH4)
/XSHUT RL: TOF7.6 (XSHUT), U6.6 (GPIO6/ADC1_CH5)
/XSHUT RR: TOF8.6 (XSHUT), U6.7 (GPIO7/ADC1_CH6)
Logic +5V GND: J1.4, J2.3, J3.1, J4.4, J5.4, J6.4, J7.4, J8.2, J8.5, J9.2, J10.3, J11.4, J12.2, J13.3, J14.2, J15.4, J16.3, J17.2, J18.4, J19.2, TOF5.2 (GND), TOF6.2 (GND), TOF7.2 (GND), TOF8.2 (GND), U6.22 (GND), U6.23 (GND), U6.24 (GND), U6.44 (GND)

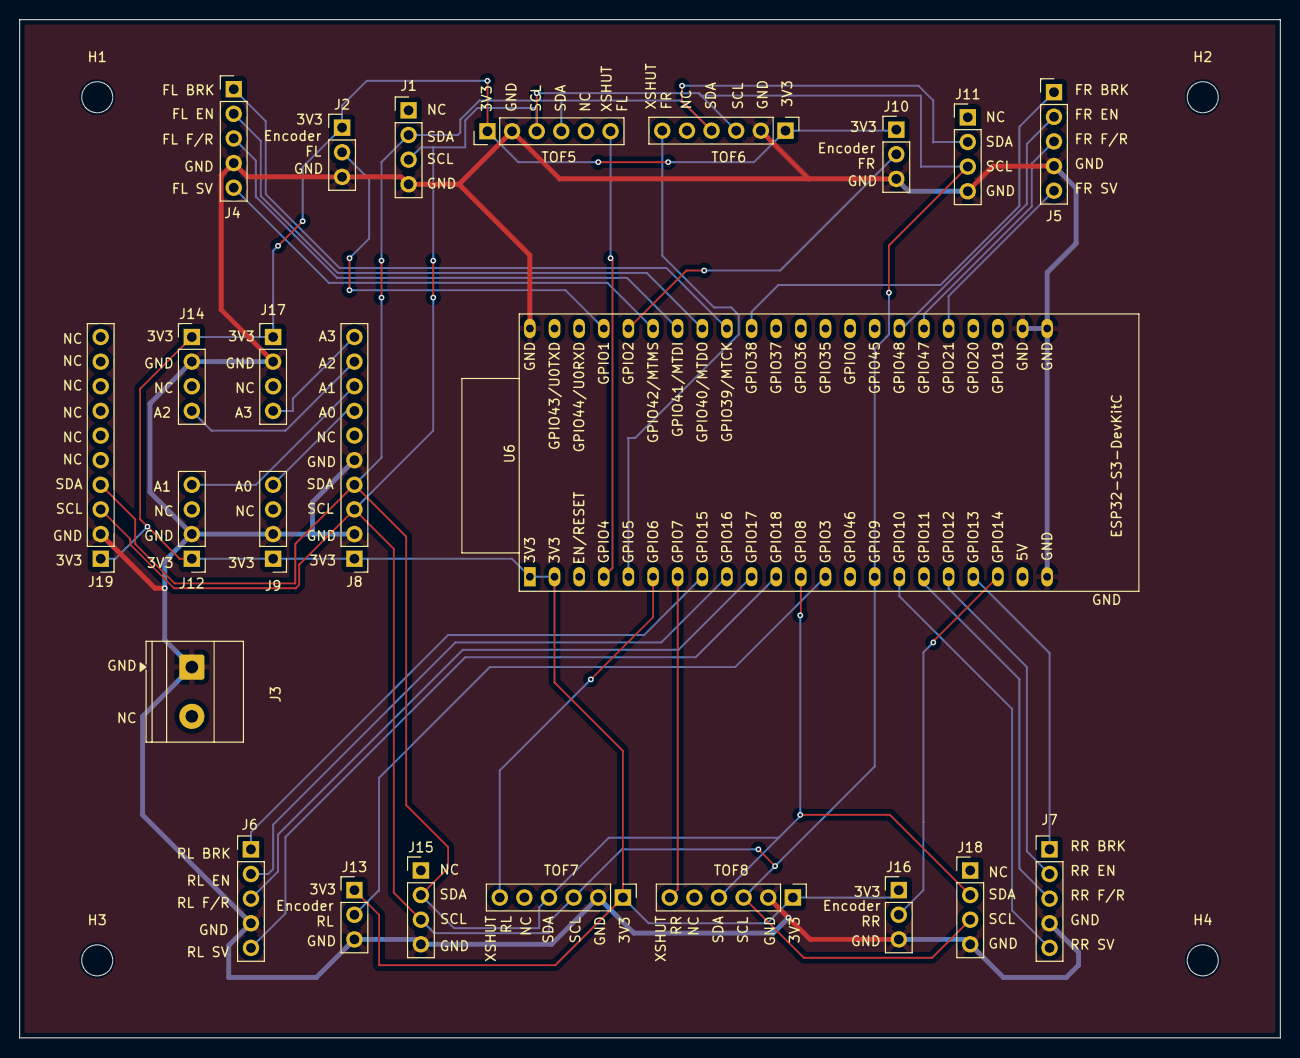
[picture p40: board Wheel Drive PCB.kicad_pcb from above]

Board: 2 copper layers, 130.0 x 105.0 mm, 28 parts (0 on the bottom side), 32 nets.

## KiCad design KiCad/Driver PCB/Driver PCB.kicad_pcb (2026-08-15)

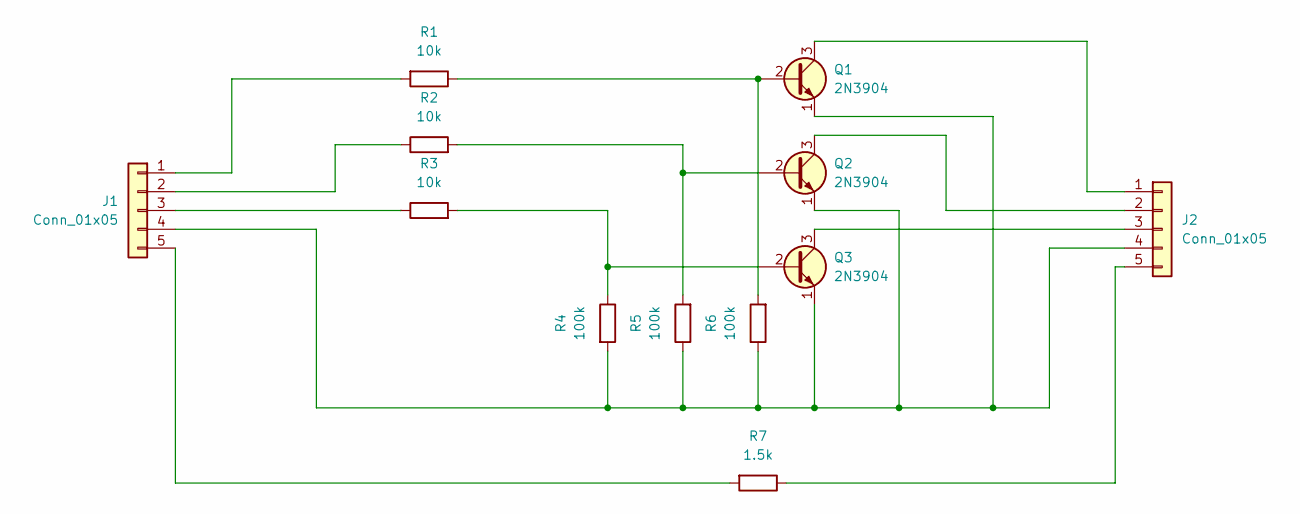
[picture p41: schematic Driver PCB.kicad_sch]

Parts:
J1, J2: Conn_01x05; PinHeader_1x05_P2.54mm_Vertical
Q1, Q2, Q3: 2N3904; TO-92_Inline_Wide_EBC
R1, R2, R3: 10k; R_Axial_DIN0207_L6.3mm_D2.5mm_P7.62mm_Horizontal
R4, R5, R6: 100k; R_Axial_DIN0207_L6.3mm_D2.5mm_P7.62mm_Horizontal
R7: 1.5k; R_Axial_DIN0207_L6.3mm_D2.5mm_P7.62mm_Horizontal

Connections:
unnamed: J1.1, R1.2
unnamed: J1.2, R2.1
unnamed: J1.3, R3.1
unnamed: J1.4, J2.4, Q1.1 (E), Q2.1 (E), Q3.1 (E), R4.2, R5.1, R6.1
unnamed: J1.5, R7.2
unnamed: J2.1, Q1.3 (C)
unnamed: J2.2, Q2.3 (C)
unnamed: J2.3, Q3.3 (C)
unnamed: J2.5, R7.1
unnamed: Q1.2 (B), R1.1, R6.2
unnamed: Q2.2 (B), R2.2, R5.2
unnamed: Q3.2 (B), R3.2, R4.1

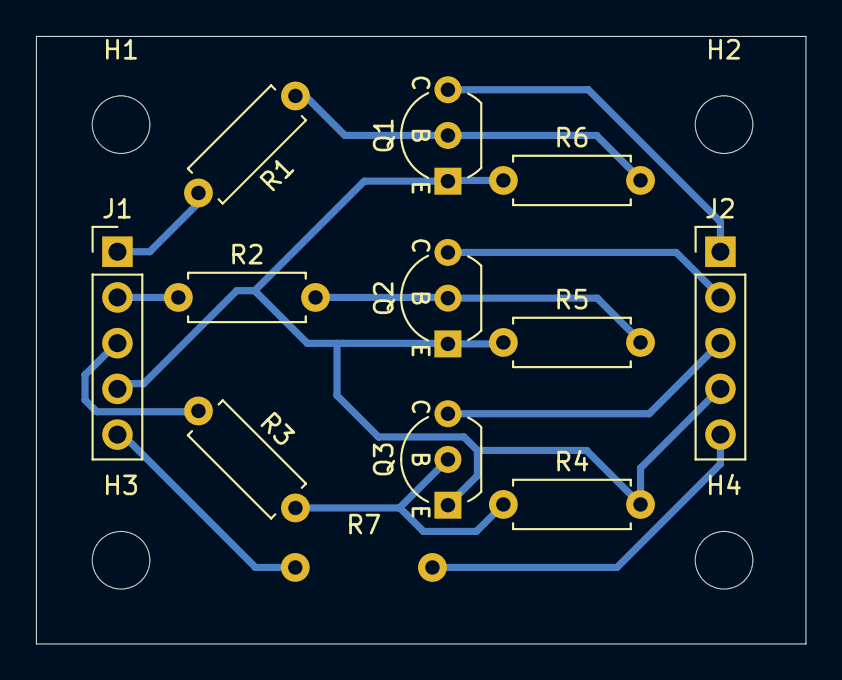
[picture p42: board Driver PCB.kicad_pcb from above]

Board: 2 copper layers, 42.8 x 33.8 mm, 16 parts (1 on the bottom side), 12 nets.

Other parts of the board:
H1, H2, H3, H4: MountingHole_3.2mm_M3

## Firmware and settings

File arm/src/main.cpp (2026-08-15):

#include <Arduino.h>
#include <WiFi.h>
#include <Wire.h>
#include <esp_now.h>
#include <esp_mac.h>
#include <esp_wifi.h>

#include "Bts7960Motor.h"
#include "HardwareConfig.h"
#include "LimitSwitches.h"
#include "MotorController.h"
#include "TofSensorArray.h"

MotorController motors;
TofSensorArray sensors;
LimitSwitches limits;
Bts7960Motor xTravelMotor;
Bts7960Motor yTravelMotor;

constexpr size_t ESPNOW_COMMAND_MAX_LEN = 32;
char pendingWirelessCommand[ESPNOW_COMMAND_MAX_LEN] = "";
uint8_t pendingWirelessSender[6] = {0};
bool hasPendingWirelessCommand = false;
uint8_t rejectedWirelessSender[6] = {0};
bool hasRejectedWirelessSender = false;

void printMacAddress(Stream &log, const char *label, const uint8_t *mac) {
  log.print(label);
  for (int i = 0; i < 6; i++) {
    if (i > 0) {
      log.print(":");
    }
    if (mac[i] < 16) {
      log.print("0");
    }
    log.print(mac[i], HEX);
  }
  log.println();
}

void printLocalMacDiagnostics(Stream &log) {
  uint8_t staMac[6] = {0};
  esp_read_mac(staMac, ESP_MAC_WIFI_STA);

  printMacAddress(log, "Arm ESP STA MAC: ", staMac);
  log.print("WiFi.macAddress(): ");
  log.println(WiFi.macAddress());
  printMacAddress(log, "Configured arm MAC: ", ARM_ESP_MAC);
  printMacAddress(log, "Trusted trolley MAC: ", TROLLEY_ESP_MAC);
}

bool macMatches(const uint8_t *a, const uint8_t *b) {
  return memcmp(a, b, 6) == 0;
}

String serialCommand;
bool clampModeEnabled = false;
unsigned long lastSensorReadMs = 0;
bool limitTestModeEnabled = false;
unsigned long lastLimitReadMs = 0;
bool hasLastLimitStates = false;
LimitSwitchStates lastLimitStates;

struct MotorJogState {
  bool active;
  bool extending;
  unsigned long startedMs;
};

MotorJogState xJog = {false, false, 0};
MotorJogState yJog = {false, false, 0};

enum class AxisCyclePhase {
  Idle,
  Extending,
  Flipping,
  Retracting,
  Done,
  Failed,
};

enum class AxisCycleMode {
  FlipRetract,
  HomeRetract,
};

struct AxisCycleState {
  bool active;
  char axis;
  AxisCycleMode mode;
  AxisCyclePhase phase;
  unsigned long phaseStartedMs;
  unsigned long lastSensorCheckMs;
};

AxisCycleState axisCycle = {
    false, 'X', AxisCycleMode::FlipRetract, AxisCyclePhase::Idle, 0, 0};
bool runYAfterXCycle = false;

enum class RemoteWorkflow {
  None,
  Grab,
  Release,
  HomeSetup,
};

RemoteWorkflow activeRemoteWorkflow = RemoteWorkflow::None;

enum class HomeSetupPhase {
  Idle,
  RetractingX,
  RetractingY,
  Done,
  Failed,
};

struct HomeSetupState {
  bool active;
  HomeSetupPhase phase;
  unsigned long phaseStartedMs;
};

HomeSetupState homeSetup = {false, HomeSetupPhase::Idle, 0};

void printHelp() {
  Serial.println();
  Serial.println("Commands:");
  Serial.println("  fx or x    = flip X servos");
  Serial.println("  fy or y    = flip Y servos");
  Serial.println("  ex         = extract/reset X servos home");
  Serial.println("  ey         = extract/reset Y servos home");
  Serial.println("  home or r  = reset all servos home");
  Serial.println("  tx         = test X sensors");
  Serial.println("  ty         = test Y sensors");
  Serial.println("  ts or s    = test all sensors");
  Serial.println("  limit      = keep testing limit switches");
  Serial.println("  xext       = jog X travel extend");
  Serial.println("  xret       = jog X travel retract");
  Serial.println("  yext       = jog Y travel extend");
  Serial.println("  yret       = jog Y travel retract");
  Serial.println("  mstop      = stop X/Y travel motors");
  Serial.println("  xcycle     = X extend, flip, retract");
  Serial.println("  ycycle     = Y extend, flip, retract");
  Serial.println("  cycle      = run X cycle then Y cycle");
  Serial.println("  xhome      = X extend to air, servo home, retract");
  Serial.println("  yhome      = Y extend to air, servo home, retract");
  Serial.println("  homecycle  = run X home workflow then Y");
  Serial.println("  home_setup = servos home, retract X/Y to min");
  Serial.println("  clamp or c = keep reading sensors and clamp valid axes");
  Serial.println("  unclamp or u = return all servos home slowly");
  Serial.println("  stop       = stop active testing modes");
  Serial.println("  help or h  = show this menu");
  Serial.println();
}

void addEspNowPeerIfNeeded(const uint8_t *mac) {
  if (esp_now_is_peer_exist(mac)) {
    return;
  }

  esp_now_peer_info_t peerInfo = {};
  memcpy(peerInfo.peer_addr, mac, 6);
  peerInfo.channel = ESPNOW_WIFI_CHANNEL;
  peerInfo.encrypt = false;
  peerInfo.ifidx = WIFI_IF_STA;

  esp_err_t result = esp_now_add_peer(&peerInfo);
  if (result != ESP_OK && result != ESP_ERR_ESPNOW_EXIST) {
    Serial.print("ESP-NOW add peer failed: ");
    Serial.println(result);
  }
}

void sendWirelessStatus(const char *status) {
  addEspNowPeerIfNeeded(TROLLEY_ESP_MAC);
  esp_err_t result = esp_now_send(
      TROLLEY_ESP_MAC, reinterpret_cast<const uint8_t *>(status),
      strlen(status) + 1);

  Serial.print("ESP-NOW status: ");
  Serial.println(status);
  if (result != ESP_OK) {
    Serial.print("ESP-NOW status send failed: ");
    Serial.println(result);
  }
}

bool isWirelessEstopPending() {
  return hasPendingWirelessCommand &&
         strncmp(pendingWirelessCommand, "estop", ESPNOW_COMMAND_MAX_LEN) == 0;
}

void onEspNowDataReceived(const uint8_t *mac, const uint8_t *data, int len) {
  if (!macMatches(mac, TROLLEY_ESP_MAC)) {
    memcpy(rejectedWirelessSender, mac, 6);
    hasRejectedWirelessSender = true;
    return;
  }

  size_t copyLen = min(static_cast<size_t>(len), ESPNOW_COMMAND_MAX_LEN - 1);
  memcpy(pendingWirelessCommand, data, copyLen);
  pendingWirelessCommand[copyLen] = '\0';
  memcpy(pendingWirelessSender, mac, 6);
  hasPendingWirelessCommand = true;
}

void beginEspNow() {
  WiFi.mode(WIFI_STA);
  esp_wifi_set_channel(ESPNOW_WIFI_CHANNEL, WIFI_SECOND_CHAN_NONE);
  printLocalMacDiagnostics(Serial);

  if (esp_now_init() != ESP_OK) {
    Serial.println("ESP-NOW init failed.");
    return;
  }

  esp_now_register_recv_cb(onEspNowDataReceived);
  addEspNowPeerIfNeeded(TROLLEY_ESP_MAC);
  Serial.println("ESP-NOW receiver ready on channel 1.");
}

void stopTravelMotors() {
  xTravelMotor.stop();
  yTravelMotor.stop();
  xJog.active = false;
  yJog.active = false;
  axisCycle.active = false;
  axisCycle.phase = AxisCyclePhase::Idle;
  homeSetup.active = false;
  homeSetup.phase = HomeSetupPhase::Idle;
  runYAfterXCycle = false;
}

void emergencyStopEverything(bool sendStatus) {
  if (sendStatus && isWirelessEstopPending()) {
    noInterrupts();
    hasPendingWirelessCommand = false;
    interrupts();
  }

  clampModeEnabled = false;
  limitTestModeEnabled = false;
  stopTravelMotors();
  motors.stopAll();
  activeRemoteWorkflow = RemoteWorkflow::None;

  Serial.println("Emergency stopped: travel motors OFF, servo PWM OFF.");
  if (sendStatus) {
    sendWirelessStatus("stopped");
  }
}

void handleRejectedWirelessSender() {
  if (!hasRejectedWirelessSender) {
    return;
  }

  uint8_t senderBuffer[6];
  noInterrupts();
  memcpy(senderBuffer, rejectedWirelessSender, 6);
  hasRejectedWirelessSender = false;
  interrupts();

  printMacAddress(Serial, "ESP-NOW rejected sender: ", senderBuffer);
}

bool isXExtendBlocked(const LimitSwitchStates &states) {
  return states.xArmMaxPressed;
}

bool isXRetractBlocked(const LimitSwitchStates &states) {
  return states.xArmMinPressed || states.limitX1Pressed || states.limitX2Pressed;
}

bool isYExtendBlocked(const LimitSwitchStates &states) {
  return states.yArmMaxPressed;
}

bool isYRetractBlocked(const LimitSwitchStates &states) {
  return states.yArmMinPressed || states.limitY1Pressed || states.limitY2Pressed;
}

void startMotorJog(char axis, bool extending) {
  clampModeEnabled = false;
  axisCycle.active = false;
  axisCycle.phase = AxisCyclePhase::Idle;
  homeSetup.active = false;
  homeSetup.phase = HomeSetupPhase::Idle;
  runYAfterXCycle = false;
  activeRemoteWorkflow = RemoteWorkflow::None;

  Bts7960Motor &motor = axis == 'X' ? xTravelMotor : yTravelMotor;
  MotorJogState &jog = axis == 'X' ? xJog : yJog;

  if (!motor.isConfigured()) {
    Serial.print(axis);
    Serial.println(" motor disabled: check BTS7960 pin config.");
    return;
  }

  LimitSwitchStates states = limits.readAll();
  bool blocked = axis == 'X'
                     ? (extending ? isXExtendBlocked(states)
                                  : isXRetractBlocked(states))
                     : (extending ? isYExtendBlocked(states)
                                  : isYRetractBlocked(states));

  if (blocked) {
    Serial.print(axis);
    Serial.print(extending ? " extend" : " retract");
    Serial.println(" blocked: matching limit is already pressed.");
    motor.stop();
    jog.active = false;
    return;
  }

  if (extending) {
    motor.setDuty(BTS_MOTOR_JOG_DUTY);
    motor.extend();
  } else {
    motor.setDuty(BTS_MOTOR_JOG_DUTY);
    motor.retract();
  }

  jog.active = true;
  jog.extending = extending;
  jog.startedMs = millis();

  Serial.print(axis);
  Serial.print(extending ? " extend" : " retract");
  Serial.println(" jog started.");
}

void serviceMotorJog(char axis, Bts7960Motor &motor, MotorJogState &jog,
                     const LimitSwitchStates &states, unsigned long now) {
  if (!jog.active) {
    return;
  }

  bool limitPressed = axis == 'X'
                          ? (jog.extending ? isXExtendBlocked(states)
                                           : isXRetractBlocked(states))
                          : (jog.extending ? isYExtendBlocked(states)
                                           : isYRetractBlocked(states));

  if (limitPressed) {
    motor.stop();
    jog.active = false;
    Serial.print(axis);
    Serial.println(" jog stopped: limit switch pressed.");
    return;
  }

  if (now - jog.startedMs >= BTS_MOTOR_JOG_TIMEOUT_MS) {
    motor.stop();
    jog.active = false;
    Serial.print(axis);
    Serial.println(" jog stopped: timeout.");
  }
}

void serviceMotorJogs() {
  if (!xJog.active && !yJog.active) {
    return;
  }

  LimitSwitchStates states = limits.readAll();
  unsigned long now = millis();
  serviceMotorJog('X', xTravelMotor, xJog, states, now);
  serviceMotorJog('Y', yTravelMotor, yJog, states, now);
}

Bts7960Motor &travelMotorForAxis(char axis) {
  return axis == 'X' ? xTravelMotor : yTravelMotor;
}

MotorJogState &jogStateForAxis(char axis) {
  return axis == 'X' ? xJog : yJog;
}

bool isAxisExtendBlocked(char axis, const LimitSwitchStates &states) {
  return axis == 'X' ? isXExtendBlocked(states) : isYExtendBlocked(states);
}

bool isAxisRetractBlocked(char axis, const LimitSwitchStates &states) {
  return axis == 'X' ? isXRetractBlocked(states) : isYRetractBlocked(states);
}

bool isAxisAirDetected(char axis, const TofReadings &readings) {
  return axis == 'X'
             ? sensors.xGroupShouldFlip(readings, SENSOR_FLIP_THRESHOLD_MM)
             : sensors.yGroupShouldFlip(readings, SENSOR_FLIP_THRESHOLD_MM);
}

bool startAxisCycle(char axis, bool queueYAfterX, AxisCycleMode mode) {
  clampModeEnabled = false;
  limitTestModeEnabled = false;
  stopTravelMotors();

  Bts7960Motor &motor = travelMotorForAxis(axis);
  if (!motor.isConfigured()) {
    Serial.print(axis);
    Serial.println(" cycle rejected: motor disabled.");
    return false;
  }

  LimitSwitchStates states = limits.readAll();
  if (isAxisExtendBlocked(axis, states)) {
    Serial.print(axis);
    Serial.println(" cycle rejected: max limit already pressed.");
    return false;
  }

  axisCycle.active = true;
  axisCycle.axis = axis;
  axisCycle.mode = mode;
  axisCycle.phaseStartedMs = millis();
  axisCycle.lastSensorCheckMs = 0;
  runYAfterXCycle = queueYAfterX;

  TofReadings readings = sensors.readAll();
  if (isAxisAirDetected(axis, readings)) {
    motor.stop();
    axisCycle.phase = AxisCyclePhase::Flipping;
    Serial.print(axis);
    Serial.println(" cycle started: air already detected, waiting before servo movement.");
    return true;
  }

  motor.setDuty(BTS_MOTOR_JOG_DUTY);
  motor.extend();
  axisCycle.phase = AxisCyclePhase::Extending;

  Serial.print(axis);
  Serial.println(" cycle started: extending.");
  return true;
}

void finishAxisCycle(bool success, const char *reason) {
  Bts7960Motor &motor = travelMotorForAxis(axisCycle.axis);
  motor.stop();
  motor.setDuty(BTS_MOTOR_JOG_DUTY);

  Serial.print(axisCycle.axis);
  Serial.print(success ? " workflow done: " : " workflow failed: ");
  Serial.println(reason);

  bool shouldStartY = success && runYAfterXCycle && axisCycle.axis == 'X';
  AxisCycleMode nextMode = axisCycle.mode;
  axisCycle.active = false;
  axisCycle.phase = success ? AxisCyclePhase::Done : AxisCyclePhase::Failed;
  runYAfterXCycle = false;

  if (shouldStartY) {
    if (!startAxisCycle('Y', false, nextMode)) {
      if (activeRemoteWorkflow == RemoteWorkflow::Grab) {
        sendWirelessStatus("failed:grab");
      } else if (activeRemoteWorkflow == RemoteWorkflow::Release) {
        sendWirelessStatus("failed:release");
      }
      activeRemoteWorkflow = RemoteWorkflow::None;
    }
    return;
  }

  if (activeRemoteWorkflow == RemoteWorkflow::Grab) {
    sendWirelessStatus(success ? "done_grab" : "failed:grab");
  } else if (activeRemoteWorkflow == RemoteWorkflow::Release) {
    sendWirelessStatus(success ? "done_release" : "failed:release");
  }

  activeRemoteWorkflow = RemoteWorkflow::None;
}

void enterRetractPhase() {
  Bts7960Motor &motor = travelMotorForAxis(axisCycle.axis);
  LimitSwitchStates states = limits.readAll();

  if (isAxisRetractBlocked(axisCycle.axis, states)) {
    finishAxisCycle(true, "already at retract limit.");
    return;
  }

  motor.setDuty(BTS_MOTOR_CYCLE_RETRACT_DUTY);
  motor.retract();
  axisCycle.phase = AxisCyclePhase::Retracting;
  axisCycle.phaseStartedMs = millis();

  Serial.print(axisCycle.axis);
  Serial.println(" cycle: retracting slowly.");
}

void serviceAxisCycle() {
  if (!axisCycle.active) {
    return;
  }

  Bts7960Motor &motor = travelMotorForAxis(axisCycle.axis);
  LimitSwitchStates limitStates = limits.readAll();
  unsigned long now = millis();

  if (axisCycle.phase == AxisCyclePhase::Extending) {
    if (isAxisExtendBlocked(axisCycle.axis, limitStates)) {
      motor.stop();
      Serial.print(axisCycle.axis);
      if (axisCycle.mode == AxisCycleMode::HomeRetract) {
        finishAxisCycle(false, "max limit pressed before air detected.");
        return;
      }
      Serial.println(" cycle: extend stopped at max limit.");
      axisCycle.phase = AxisCyclePhase::Flipping;
    } else if (now - axisCycle.lastSensorCheckMs >=
               AXIS_CYCLE_SENSOR_READ_INTERVAL_MS) {
      axisCycle.lastSensorCheckMs = now;
      TofReadings readings = sensors.readAll();

      if (isAxisAirDetected(axisCycle.axis, readings)) {
        motor.stop();
        Serial.print(axisCycle.axis);
        Serial.println(" cycle: extend stopped, air detected. Waiting before servo movement.");
        axisCycle.phase = AxisCyclePhase::Flipping;
      }
    }

    if (axisCycle.phase == AxisCyclePhase::Flipping) {
      axisCycle.phaseStartedMs = millis();
      return;
    }

    if (now - axisCycle.phaseStartedMs >= BTS_MOTOR_CYCLE_TIMEOUT_MS) {
      finishAxisCycle(false, "extend timeout.");
    }
    return;
  }

  if (axisCycle.phase == AxisCyclePhase::Flipping) {
    if (now - axisCycle.phaseStartedMs < AXIS_CYCLE_SERVO_DELAY_MS) {
      return;
    }

    motor.stop();
    Serial.print(axisCycle.axis);
    Serial.println(axisCycle.mode == AxisCycleMode::HomeRetract
                       ? " workflow: returning servos home."
                       : " cycle: flipping servos.");

    if (axisCycle.axis == 'X') {
      if (axisCycle.mode == AxisCycleMode::HomeRetract) {
        if (!motors.extractXAxis(isWirelessEstopPending)) {
          emergencyStopEverything(true);
          return;
        }
      } else {
        if (!motors.flipXAxis(isWirelessEstopPending)) {
          emergencyStopEverything(true);
          return;
        }
      }
    } else {
      if (axisCycle.mode == AxisCycleMode::HomeRetract) {
        if (!motors.extractYAxis(isWirelessEstopPending)) {
          emergencyStopEverything(true);
          return;
        }
      } else {
        if (!motors.flipYAxis(isWirelessEstopPending)) {
          emergencyStopEverything(true);
          return;
        }
      }
    }

    enterRetractPhase();
    return;
  }

  if (axisCycle.phase == AxisCyclePhase::Retracting) {
    if (isAxisRetractBlocked(axisCycle.axis, limitStates)) {
      finishAxisCycle(true, "retract limit pressed.");
      return;
    }

    if (now - axisCycle.phaseStartedMs >= BTS_MOTOR_CYCLE_TIMEOUT_MS) {
      finishAxisCycle(false, "retract timeout.");
    }
  }
}

void finishHomeSetup(bool success, const char *reason) {
  xTravelMotor.stop();
  yTravelMotor.stop();
  xTravelMotor.setDuty(BTS_MOTOR_JOG_DUTY);
  yTravelMotor.setDuty(BTS_MOTOR_JOG_DUTY);

  homeSetup.active = false;
  homeSetup.phase = success ? HomeSetupPhase::Done : HomeSetupPhase::Failed;

  Serial.print(success ? "Home setup done: " : "Home setup failed: ");
  Serial.println(reason);

  if (activeRemoteWorkflow == RemoteWorkflow::HomeSetup) {
    sendWirelessStatus(success ? "done_home" : "failed:home_setup");
  }
  activeRemoteWorkflow = RemoteWorkflow::None;
}

void startHomeSetupRetractY() {
  LimitSwitchStates states = limits.readAll();
  if (isYRetractBlocked(states)) {
    finishHomeSetup(true, "Y already at min/home.");
    return;
  }

  yTravelMotor.setDuty(BTS_MOTOR_CYCLE_RETRACT_DUTY);
  yTravelMotor.retract();
  homeSetup.phase = HomeSetupPhase::RetractingY;
  homeSetup.phaseStartedMs = millis();
  Serial.println("Home setup: retracting Y slowly.");
}

void startHomeSetupRetractX() {
  LimitSwitchStates states = limits.readAll();
  if (isXRetractBlocked(states)) {
    Serial.println("Home setup: X already at min/home.");
    startHomeSetupRetractY();
    return;
  }

  xTravelMotor.setDuty(BTS_MOTOR_CYCLE_RETRACT_DUTY);
  xTravelMotor.retract();
  homeSetup.phase = HomeSetupPhase::RetractingX;
  homeSetup.phaseStartedMs = millis();
  Serial.println("Home setup: retracting X slowly.");
}

bool startHomeSetup() {
  clampModeEnabled = false;
  limitTestModeEnabled = false;
  stopTravelMotors();

  if (!xTravelMotor.isConfigured() || !yTravelMotor.isConfigured()) {
    Serial.println("Home setup rejected: travel motor config missing.");
    return false;
  }

  homeSetup.active = true;
  homeSetup.phase = HomeSetupPhase::Idle;
  homeSetup.phaseStartedMs = millis();

  Serial.println("Home setup: returning servos home slowly.");
  if (!motors.resetAllToHome(isWirelessEstopPending)) {
    emergencyStopEverything(true);
    return false;
  }

  startHomeSetupRetractX();
  return true;
}

void serviceHomeSetup() {
  if (!homeSetup.active) {
    return;
  }

  LimitSwitchStates states = limits.readAll();
  unsigned long now = millis();

  if (homeSetup.phase == HomeSetupPhase::RetractingX) {
    if (isXRetractBlocked(states)) {
      xTravelMotor.stop();
      xTravelMotor.setDuty(BTS_MOTOR_JOG_DUTY);
      Serial.println("Home setup: X min/home reached.");
      startHomeSetupRetractY();
      return;
    }

    if (now - homeSetup.phaseStartedMs >= BTS_MOTOR_CYCLE_TIMEOUT_MS) {
      finishHomeSetup(false, "X retract timeout.");
    }
    return;
  }

  if (homeSetup.phase == HomeSetupPhase::RetractingY) {
    if (isYRetractBlocked(states)) {
      finishHomeSetup(true, "Y min/home reached.");
      return;
    }

    if (now - homeSetup.phaseStartedMs >= BTS_MOTOR_CYCLE_TIMEOUT_MS) {
      finishHomeSetup(false, "Y retract timeout.");
    }
  }
}

bool limitStatesChanged(const LimitSwitchStates &current,
                        const LimitSwitchStates &previous) {
  return current.limitX1Pressed != previous.limitX1Pressed ||
         current.limitX2Pressed != previous.limitX2Pressed ||
         current.limitY1Pressed != previous.limitY1Pressed ||
         current.limitY2Pressed != previous.limitY2Pressed ||
         current.xArmMinPressed != previous.xArmMinPressed ||
         current.xArmMaxPressed != previous.xArmMaxPressed ||
         current.yArmMinPressed != previous.yArmMinPressed ||
         current.yArmMaxPressed != previous.yArmMaxPressed;
}

void printLimitSwitchStates(const LimitSwitchStates &states) {
  limits.printStates(states, Serial);
  Serial.println("------------------------------");
}

void startLimitTestMode() {
  clampModeEnabled = false;
  limitTestModeEnabled = true;
  lastLimitReadMs = 0;
  hasLastLimitStates = false;
  Serial.println("Limit switch test ON. Fast polling, printing only changes. Type stop to end.");

  lastLimitStates = limits.readAll();
  hasLastLimitStates = true;
  printLimitSwitchStates(lastLimitStates);
}
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
void loop() {
  handleRejectedWirelessSender();
  handleWirelessCommand();
  handleSerialCommand();
  serviceMotorJogs();
  serviceAxisCycle();
  serviceHomeSetup();

  unsigned long now = millis();
  if (clampModeEnabled && now - lastSensorReadMs >= SENSOR_READ_INTERVAL_MS) {
    lastSensorReadMs = now;
    checkClampSensors();
  }

  if (limitTestModeEnabled &&
      now - lastLimitReadMs >= LIMIT_SWITCH_READ_INTERVAL_MS) {
    lastLimitReadMs = now;

    LimitSwitchStates currentStates = limits.readAll();
    if (!hasLastLimitStates ||
        limitStatesChanged(currentStates, lastLimitStates)) {
      lastLimitStates = currentStates;
      hasLastLimitStates = true;
      printLimitSwitchStates(currentStates);
    }
  }
}

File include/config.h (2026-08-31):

// Tunable parameters for the firmware. Kept out of the pure domain so the domain
// stays generic; main.cpp uses these to build the domain config structs.
#pragma once

#include <cstdint>

#include "CornerEdgeDetector.h"
#include "DeadReckonOdometry.h"
#include "DockingStateMachine.h"
#include "LinkWatchdog.h"

namespace cfg {

// --- Loop timing ---
constexpr uint32_t kControlPeriodMs = 20;     // 50 Hz control tick
constexpr uint32_t kTelemetryPeriodMs = 200;  // 5 Hz status publish

// --- Alignment sensor layout: 4 corner ToF, XSHUT re-addressing (NOT a mux) ---
// Zone index order MUST match Corner: FL=0, FR=1, RL=2, RR=3.
//
// The mux constants that used to live here described the ENCODER branches, not
// the ToF -- pointing the ToF driver at them was a real bug, fixed 2026-08-11
// (see the comment on g_tof in src/main.cpp). They are gone with the encoders,
// as is pins::kMuxAddr itself (removed 2026-08-31).
constexpr uint8_t kNumZones = 4;

// --- Clamp safety ---
constexpr float kClampStallAmps = 4.0f;  // over-current -> fault (calibrate on bench)

// Per-wheel over-current trip, from the ACS758 -> ADS1115 chain.
//
// The BLD-120A is rated 8 A continuous, 30 A instantaneous (<3 s). 10 A sits
// above any legitimate running current -- the bench measured roughly 0.2 A per
// wheel unloaded -- while staying well under the driver's own instantaneous
// rating, so this trips on something genuinely wrong rather than on a hill.
//
// *** NOT CALIBRATED UNDER LOAD. *** Measured only with wheels off the ground
// on 2026-08-11. Re-check with a loaded trolley before trusting it to protect
// anything, and remember the sensor cannot tell a stall from a heavy load.
constexpr float kWheelStallAmps = 10.0f;

// PER-CORNER ToF OFFSET, in mm, added to every valid reading. FL, FR, RL, RR.
//
// Regenerate with the View button on the gamepad (bench_ble), which averages 16
// frames and prints a replacement for this line.
//
// DERIVED 2026-08-13 from steady all-four-present frames under the trolley:
// FL 78.7, FR 125.1, RL 103.7, RR 102.0. Referenced to FL, so all four now
// report ~78 for the same gap.
//
// These stopped being cosmetic the moment the bands had to separate a real
// return from an edge artefact. Uncorrected, legitimate readings spanned 74-138
// while artefacts at the edge ran 131-296 -- overlapping, so no threshold could
// split them. Corrected, real coverage collapses to ~70-88 and the nearest
// artefact sits at ~108, which a ceiling can get between.
//
// Re-capture with the View button if the brackets are ever disturbed; these came
// off logged frames rather than the averaging routine, so treat them as good to
// a couple of mm, not better.
constexpr int16_t kTofOffsetMm[4] = {0, -46, -25, -23};

// Corner edge detection: the solid board sits within this height band above the
// up-facing sensors. Tune on the bench.
inline fal::CornerConfig makeCornerConfig() {
  fal::CornerConfig c;
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

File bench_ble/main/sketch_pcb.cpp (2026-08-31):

// Bluepad32 gamepad drive for the FABRICATED Wheel Drive PCB.
//
// WHY THE BREADBOARD PIN TABLE IS NOT REUSED
// ------------------------------------------
// The breadboard sketches (sketch_bld.cpp and their shared drive header, both
// removed 2026-08-31) used a pin table measured on the BREADBOARD. On the
// fabricated board two corners have their roles exactly swapped:
//
//     GPIO21   bench: FR brake        pins.h: FR speed PWM
//     GPIO38   bench: FR speed PWM    pins.h: FR brake
//     GPIO15   bench: RL speed PWM    pins.h: RL brake
//     GPIO18   bench: RL brake        pins.h: RL speed PWM
//
// Flashing it here would send speed PWM into two brake lines and hold two speed
// inputs as enables. This file reads include/pins.h -- the netlist-derived map --
// and never a hand-typed table.
//
// THE ARM IS REACHED BY ESP-NOW, NOT BY WIRE
// ------------------------------------------
// The three-wire UART on GPIO1/2 never passed a byte and was retired 2026-08-14.
// Commands now go out as plain NUL-terminated text over ESP-NOW on channel 1:
// "grab", "release", "home_setup", "estop", and nothing else. The arm is already
// flashed to parse exactly those, so the strings are an interface.
//
// CONTROLS
//   DRIVE   left stick   move / strafe      right stick X  rotate
//           D-pad        8-way translation  LB / RB        slower / faster
//   DOCK    A            run the real ToF alignment, auto-grab on confirm
//   ARM     X  grab      Y  release         Menu  home_setup
//           LT (hold) + D-pad  jog X/Y, held = moves, released = stops
//           RT (hold) + D-pad  flip pairs, one shot, ~2 s, no reply
//   STOP    B            E-STOP: arm AND local wheels
//   SENSE   L3 ToF stream    R3 read corners    View capture ToF offsets
//
// SAFETY
//   * no gamepad at boot -> motors stay disabled; nothing spins on power-up
//   * gamepad disconnect -> wheels stop
//   * B stops BOTH boards, and bypasses the busy interlock: an E-stop that a
//     status message can suppress is not an E-stop
//   * drive speed is capped at 40% -- there is no stall detection on this base
//   WHEELS OFF THE GROUND.
#include <Arduino.h>
#include <Bluepad32.h>
#include <Wire.h>
#include <WiFi.h>
#include <esp_now.h>
#include <esp_wifi.h>
#include <string.h>

#include "bench_mix.h"   // pure mecanum mix, shared with the bench rigs
#include "config.h"
#include "pins.h"        // NETLIST-DERIVED. never hand-type a pin table.

// The REAL alignment stack, reused rather than reimplemented. These are the
// same classes main.cpp runs and the same ones covered by the 70 host tests --
// a second copy of a docking state machine is the last thing this project needs.
#include "ArduinoClock.h"
#include "CornerEdgeDetector.h"
#include "DockFrame.h"
#include "DeadReckonOdometry.h"
#include "DockingStateMachine.h"
#include "SafetyMonitor.h"
#include "Vl53l0xArray.h"

using namespace fal;

// Adapter polarity. The NPN stage INVERTS: HIGH at the GPIO asserts the driver
// input. The output latch resets LOW, so every line boots released and the
// motors boot disabled -- the safe state is the power-on default.
static constexpr uint8_t ASSERT_LVL = HIGH, RELEASE_LVL = LOW;
static constexpr uint8_t FWD_LVL = LOW, REV_LVL = HIGH;
static constexpr uint32_t PWM_HZ = 2000;      // inside BOTH driver manuals' ranges
static constexpr uint8_t PWM_BITS = 12;
static constexpr uint16_t PWM_MAX = (1u << PWM_BITS) - 1u;

static const char* WHEEL[4] = {"FL", "FR", "RL", "RR"};

// PER-WHEEL DIRECTION CALIBRATION.
//
// VERIFIED ON THE ASSEMBLED BASE 2026-08-11: with an empty table both LEFT
// wheels ran backwards, so FL and RL need their F/R line flipped for a forward
// command to drive forward. The left-hand motors are mounted mirrored to the
// right-hand pair -- a mechanical fact about the chassis, not a wiring error.
//
// This is NOT inherited from the breadboard rig's table (which happened to hold
// the same values): bench "FL" is this board's RR and its two middle corners
// were driving the wrong lines entirely, so that calibration described nothing.
// This one was re-derived here, on this hardware.
static bool g_invert[4] = {true, false, true, false};   // FL FR RL RR

static bool g_rev[4] = {false, false, false, false};
static uint16_t g_duty[4] = {0, 0, 0, 0};

static ControllerPtr g_ctl = nullptr;
static bool g_pairing = false;
static uint8_t g_cal_sel = 0;
// Set ONLY by a real ToF confirmation now. It was a manual override on Y until
// 2026-08-14, when Y became the arm's "release"; the status line still shows it
// because "this base believes it is aligned" is worth seeing at a glance.
static bool g_sim_aligned = false;

// SPEED LIMITS -- CEILING IS 40%, ON PURPOSE.
// There is no encoder feedback and no stall detection on this base (no ALARM
// terminal, encoders deferred), so nothing in software can tell a jammed wheel
// from a loaded one. 40% of a drivetrain that reaches ~1400 mm/s is plenty for
// manual work and leaves the operator time to react.
static const float LIMITS[] = {0.10f, 0.20f, 0.30f, 0.40f};
static uint8_t g_limit_idx = 0;

// ---- link to ESP-ARM: ESP-NOW, replacing the three-wire UART ---------------
//
// The UART link on GPIO1/2 never passed a byte and was retired 2026-08-14. This
// is radio instead: no wires, no crossing to get backwards, and it works whether
// or not the arm's USB cable is plugged in.
//
// THE COST IS REAL AND WORTH STATING. Bluepad32/BTstack owns the 2.4 GHz radio
// for the gamepad; bringing up WiFi STA makes them share it through the
// coexistence scheduler. Expect the pad to be slightly less responsive and to
// drop marginally more often than it did on the UART build. If that becomes
// intolerable the answer is to fix the wires, not to tune this.
//
// PROTOCOL: plain text, NUL-terminated, four commands and no more. No JSON, no
// structs, no versioning -- the arm's receiver is already flashed and parses
// exactly these, so the strings are an interface, not an implementation detail.
//
//     "grab"        "release"        "home_setup"        "estop"
//
// Replies come back as text too: done_grab, done_release, done_home, busy,
// stopped, failed:<reason>, rejected:<reason>.
static const uint8_t ARM_ESP_MAC[6] = {0x3C, 0xDC, 0x75, 0x5C, 0x8B, 0x08};

// This board's own MAC, checked at boot. Flashing base firmware onto the arm (or
// vice versa) is a five-second mistake that presents as "the link is dead", and
// we have already spent an evening on a link that was dead for other reasons.
static const uint8_t SELF_ESP_MAC[6] = {0x14, 0xC1, 0x9F, 0x3B, 0x7B, 0xE4};

// WiFi channel. ESP-NOW peers must agree, and since neither board joins an AP
// nothing will move us off it -- but it has to be set explicitly, because the
// default depends on prior NVS state rather than on anything in this file.
static constexpr uint8_t ARM_WIFI_CHANNEL = 1;
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

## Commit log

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2026-07-06 Redesign alignment: 4-corner edge + odometry (solid board)
    The trolley base is now a guaranteed solid board, so ToF returns are
    continuous — the windowed-confidence AlignmentInterpreter is removed and
    replaced by a deterministic geometric procedure over 4 corner sensors.
    - CornerEdgeDetector: debounced per-corner "board present" (FL/FR/RL/RR).
    - DeadReckonOdometry (new IOdometry port): integrates commanded velocity;
    centring drives to the midpoint between two edge events so calibration
    scale cancels. FG wheel-pulse upgrade reserved on GPIO 40/41/42/48.
    - DockingStateMachine reworked: APPROACH -> ORIENT (rotate until both front
    corners see the edge) -> CENTER_X -> CENTER_Y -> CONFIRM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
    [config.h, main.cpp]
2026-07-10 Add bench BLE gamepad control design spec
    Xbox BLE controller via Bluepad32 as a manual-drive input for the bench
    rig, layered on the existing serial WASD + auto-align. Captures the
    S3-is-BLE-only constraint (Switch pads can't pair), the benchpad env +
    USE_GAMEPAD structure, proportional driveMixF, serial/gamepad coexistence
    with if(Serial) untether-safety, and the disconnect + watchdog fail-safe.
2026-07-10 Correct BLE spec architecture: Bluepad32 needs ESP-IDF template + shared core
    Bluepad32-on-Arduino via PlatformIO is an ESP-IDF+Arduino-component project
    (pioarduino platform, components/ submodules), not a stock Arduino env. So
    the gamepad build is a separate bench_ble/ project, and the bench drivetrain/
    sensor/align logic is factored into a shared header-only core (bench_core.h)
    that both the serial build and the gamepad build include. Also pins the Xbox
    1914 / firmware >= v5.15 facts from Bluepad32 docs.
2026-07-10 Checkpoint validated bench rig: WASD teleop + auto-align, native USB CDC
    - src/bench_check.cpp: standalone bench sketch (2 ToF + 4 mecanum/L298N),
    serial WASD jog, per-wheel direction calibration, O-config mecanum mix,
    and auto edge-align (ORIENT -> CENTER_X) with dead-reckon odometry centring.
    - platformio.ini: [env:bench] routes Serial to native USB (usbmodem) via
    ARDUINO_USB_CDC_ON_BOOT=1 / ARDUINO_USB_MODE=1; monitor_port -> usbmodem.
    - teleop.py: raw-stdin keyboard teleop (pio device monitor is broken on this host).
    - src/tof_scan.cpp: standalone ToF bring-up program.
    - docs/.../2026-07-08-trolleybot-bench-auto-align-design.md: 2-sensor auto-align spec.
    Known-good baseline before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
    [teleop.py, tof_scan.cpp]
2026-07-13 fix(bench): reject VL53L0X no-target glitches that false-fired auto-align
    Sensor B emitted spurious short reads (~159mm on open air) that passed the
    20-500mm band test and auto-triggered ORIENT/CENTER_X at boot (parked in
    CENTERED with x!=0 before anything was placed). Filter every reading on the
    device range-status byte (reg 0x14, status 11 = valid) so no-target/signal-fail
    measurements are rejected before the band test. Also arm the auto-trigger only
    after a confirmed clear baseline. Verified on hardware: mode stays MANUAL,
    B reads oor, x=0.
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2026-07-13 feat(bench_ble): Xbox gamepad drives the mecanum rig (verified) + persistent pairing
    Manual proportional mecanum drive from an Xbox BLE pad via a new shared,
    header-only drivetrain: src/bench_mix.h (pure host-testable mix) + src/bench_drive.h
    (pin map, invert mask, wheel, driveMixF) — one source of truth usable by both this
    build and the serial bench firmware. Left stick = translate, right stick X = rotate;
    12% deadzone absorbs drift; BLE disconnect -> stopAll fail-safe. main/CMakeLists.txt
    adds ../../src to INCLUDE_DIRS. Persistent pairing (dropped forgetBluetoothKeys) so
    the pad auto-reconnects untethered. Verified on hardware: drives correctly, signs OK.
    Drive-only (ToF/auto-align port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
2026-07-13 feat(bench_ble): auto-align on the gamepad build -- A enables, B disables
    Ports the 2-sensor edge-align (ORIENT -> CENTER_X) into the Bluetooth build via a
    new pure, print-free shared core (src/bench_align.h): ToF bring-up, range-status
    glitch filter, presence debounce, the state machine, and dead-reckon odometry,
    driving through bench_drive.h. Vendors the Pololu VL53L0X as an ESP-IDF component
    (bench_ble/components/VL53L0X + CMakeLists; gitignore exception so it is tracked
    while the Bluepad32 submodules stay ignored). Gamepad frontend: A rising edge ->
    auto-align ON, B -> OFF + abort; disconnect -> abort + stop. Verified on hardware:
    builds, boots, ToF reads (~8190 oor with nothing overhead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
2026-07-13 feat(bench_align): anti-stall kickstart + pivot-comp ORIENT; align/manual tuning
    - Pause-then-symmetric-kickstart before every align move-from-rest: settle to a
    common friction state, then a brief full-duty pulse to break stiction, so both
    sides launch together instead of one lurching first. odoStep now scales by duty
    so the kick burst counts at ~its real speed, keeping the CENTER_X midpoint
    consistent between seek and return.
    - Pivot-comp ORIENT: bias the rotation to pivot about the leading (already-detected)
    sensor via a forward term (gain c/L_char = 26.25/151.25 ~= 0.17) so the reference
    sensor doesn't drift off the edge and cant. Sign/gain verify-on-hardware.
    - Align duty 180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
2026-07-15 docs(research): save caster-load mechanics report + realignment concept
    Persist the standalone research so it can be picked up later; no
    firmware/source changes.
    - docs/research/2026-07-13-caster-load-mechanics.md: cited report on moving
    a 4-swivel-caster trolley (<=200 kg). Key finding: the binding constraint
    is the robot's own mecanum-wheel traction (not motor torque); a light
    pusher physically cannot start the load, so the clamp must transfer
    weight/lift rather than only grip. [V]/[S]/[E] confidence tags throughout.
    - docs/concepts/2026-07-14-caster-realignment-current-wiggle.md: parked
    "detect-and-wiggle" caster-realignment concept + resolved sensor plan
    (halls/FG + IMU; AS5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
2026-07-26 feat(bench_motor): BLD-120A bench rig with AS5600 closed-loop feedback
    Bench bring-up firmware for a single BLD-120A + BLDC motor on a plain
    ESP32-WROOM-32D devkit (not the S3 used everywhere else in this repo).
    Serial console with one-key dispatch so `x` e-stops on keypress rather than
    waiting for Enter. SV is driven from DAC1/GPIO25; the driver exposes no FG and
    no ALM, so the rig was fully open-loop until the encoder landed.
    AS5600 on GPIO21/22 (not the 38/39 in pins.h -- those are S3 pins; GPIO39 is
    input-only on this chip and GPIO38 is not bonded out). Closes the loop and
    makes software stall detection possible for the first time.
    Bench-measured 2026-07-27: SV->RPM is linear at 1012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
2026-07-26 docs(bench): motor calibration spec + plan, and correct a false safety claim
    Adds the 3-phase calibration design (SV->RPM transfer curve, step response,
    15:1 gearbox verification) and its implementation plan.
    Also corrects a safety claim in the bring-up handoff plan. That document told
    the reader to set a ~1A PSU current limit and called it "the only safety net".
    The bench PSU has no current limit at all. The real protection chain is the
    driver's Peak Power trim (<=8A, position unverified) then a 10A fuse -- and
    the fuse cannot protect the motor, because an 8A stall sits below it
    indefinitely while 192W goes into stationary windings.
    This mattered because the document opens with "read top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
2026-07-26 feat(bench): add StallDetector — software fault trip for the BLD-120A rig
    The bench PSU has no current limit and the BLD-120A has no ALM/FG output,
    so a locked rotor can sink ~192 W into stationary windings undetected
    (8 A sits below the 10 A fuse indefinitely). StallDetector is the pure
    host-tested logic that trips on "commanded to move, not moving" rather
    than on current, so it won't false-trip on legitimate inrush.
    9/9 unit tests passing under `pio test -e native -f test_stall_detector`.
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2026-07-26 fix(bench): kneeCmd must skip points below rpm_floor, not just predicted<=0
    The predicted<=0.0f guard alone only skips cmd 0 for a fit through the
    origin. On a realistic sweep (dead below break-away, then linear), a
    stationary point at cmd 8 still has a positive predicted RPM, so it reads
    as a 100% departure from the fit and kneeCmd returns the first non-zero
    command instead of the real knee or -1.
    Give kneeCmd an explicit rpm_floor parameter, matching breakAwayCmd/
    dropOutCmd, and skip any point whose |rpm| is below it before evaluating
    the fit. Update the header doc comment to say plainly that points below
    rpm_floor are skipped, update the two existing knee tests to pass a floor
    of 5.0f,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
    [test_motor_cal_analysis.cpp]
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2026-07-27 fix(bench_motor): pre-merge review fixes for stall trip and cal guards
    Six fixes from final pre-merge review, all touching the same safety-critical
    surface: this rig has no PSU current limit and no driver fault output, so the
    software stall trip is the only automatic protection, and it has never run
    on real hardware.
    1. Boot banner and printStatus() no longer claim stall-trip protection when
    the encoder is absent (g_encOk gates the whole trip block in loop(), so
    without it manual driving was silently unprotected) -- now prints a loud
    warning instead, on every status line, not just once at boot.
    2. calBusy() now also gates s/v/+/-/z/e, which all write g_targetSv,
    g_enabled, or g_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
    [test_motor_cal_analysis.cpp]
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2026-08-06 feat(domain): LinkWatchdog -- dead-man's handle on the Pi link
    Requires continuous proof the Pi is alive; brakes when it stops arriving.
    Boots NEVER_SEEN so motors stay disabled through the Pi's ~30 s boot. Trips
    after 100 ms. LATCHES: a recovered link must not resume motion, because the Pi
    was commanding against sensor data it stopped receiving. RESUME is refused
    unless the link currently carries fresh traffic, so a buffered RESUME cannot
    re-enable motors down a cable that is still unplugged.
    Elapsed-time maths is unsigned subtraction, correct across the millis()
    rollover at 49.7 days. 17 host tests, each naming the failure it prevents.
    [test_link_watchdog.cpp]
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2026-08-06 fix(pins): rebuild pins.h from the PCB netlist; document the hardware
    The map in pins.h was PRE-PCB DESIGN INTENT and did not match the fabricated
    board: SV on GPIO4-7 (actually the ToF XSHUT lines) and I2C on 38/39 (actually
    FR BRK and FL BRK). Flashing it would have driven the I2C bus as motor enables.
    Now extracted from Wheel Drive PCB.net -- 26 GPIO, no duplicates, no conflicts.
    EN/BRK are PER-WHEEL on the fabricated board, not ganged as designed.
    kWheelALARM is now kNoPin: the BLD-120A exposes no ALM terminal, so fault()
    was reading a floating pull-up as a permanent all-clear.
    Bld120aMotor: writes the safe level BEFORE pinMode, because the output latch
    resets to 0 and 0 on an active-l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
    [pins.h]
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2026-08-06 feat(pi): serial bridge, mecanum mixing and gamepad teleop
    pi/mecanum.py is a faithful port of MecanumDrive.cpp with assertions that
    encode the sign convention, so flipping a sign during bring-up fails a check
    rather than silently disagreeing with the firmware.
    pi/bridge.py ticks at a fixed 50 Hz and never waits for a frame -- a late ESP
    becomes a degraded reading, not a stalled control loop. pi/fake_esp.py speaks
    the firmware's wire protocol over a PTY so the bridge can be debugged with no
    hardware; the full cycle (heartbeat, silence, latch, RESUME) passes.
    pi/gamepad.py reads an Xbox pad via evdev, carrying over the deadzone and axis
    convention from bench_ble unchanged so the robot feels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
    [teleop.py]
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2026-08-06 fix: five blockers from PR review
    1. env:esp32s3 DID NOT COMPILE. The netlist rebuild of pins.h dropped ten
    symbols main.cpp uses and made kWheelEN/kWheelBRK arrays. Restoring the old
    values would have been worse: on the fabricated board GPIO11/12/13 are RR
    F/R, RR EN and RR BRK, so the clamp would have fought the rear-right wheel.
    The board has no clamp, limit-switch or E-stop connector at all -- that is
    ESP-ARM's job, and it is not built. They are now kNoPin, and Bts7960Clamp /
    GpioLimitSwitches no-op on kNoPin as Bld120aMotor already did for ALARM.
    env:esp32s3 also compiled every src/bench_*.cpp; now main.cpp only, which is
    what hid the breakage behind unrelated AS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
    [main.cpp, pins.h, test_link_watchdog.cpp]
2026-08-06 docs: discard the untrusted bench measurements
    Several multimeter readings taken during bring-up contradicted each other
    (EN->COM open in both directions unpowered, then conducting when powered)
    and the conditions were not controlled. Rather than reconcile them, remove
    them from pins.h and Bld120aMotor.h and mark the derived claims UNVERIFIED
    in the snapshot.
    Nothing depended on them. Fitting the adapters, kControlViaMosfet = true
    and 2 kHz PWM are each justified by the manuals and confirmed by four
    working drivers -- behaviour, not a meter reading.
    Also fixes two stale comments in Bld120aMotor.h that predated the PCB:
    EN/BRK described as ganged (they are per-wheel) and the control lines
    d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
    [pins.h]
2026-08-08 feat: PCB board-test rig for qualifying manufactured Wheel Drive boards
    Adds env:pcb_rl -- the first bench firmware that reads include/pins.h rather
    than a hand-typed pin table. That matters: bench_bld_drive.h and pins.h
    disagree about FR and RL (the four roles are in opposite order), so pointing a
    breadboard rig at the fabricated board sends speed PWM to the brake line.
    Firmware (src/bench_pcb_rl.cpp):
    t RL self-test, 5-20% duty both directions, keypress aborts
    s signal scan of all 16 wheel control lines -- shorts and bridges, no motor
    w meter walk, holds each line 4 s for probing (24 V OFF)
    Host (tools/board_test.py): per-board loop with boot-mode check, scan compared
    against a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
    [board_test_log.csv]
2026-08-11 feat: base bring-up — discover the corner map, fix the ToF path, add IMU and current sensing
    Brings the assembled base up against the fabricated Wheel Drive PCB and wires in
    the two sensors that were on the board but absent from firmware.
    FIXES A BUG THAT WOULD HAVE BEEN NASTY TO FIND ON A MOVING ROBOT
    main.cpp built its ToF array as Vl53l0xMux on cfg::kMuxChannels = {0,1,2,3}.
    Two things were wrong with that on this board: the netlist wires the four
    VL53L0X for XSHUT sequencing on GPIO4-7 with no mux involved, and channels 0-3
    of the mux are the AS5600 ENCODERS. Alignment ranging was aimed at the encoder
    branches. Swapped to Vl53l0xArray; both implement IAlignmentSensor so nothing
    downst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
    [board_test_log.csv]
2026-08-12 feat: gamepad-driven docking on the fabricated PCB, plus the arm UART link
    sketch_pcb.cpp is the first bench firmware that reads include/pins.h instead
    of a hand-measured table. That matters: on the fabricated board the FR and RL
    corners have SV and BRK swapped relative to the breadboard, so sketch_bld.cpp
    would drive speed PWM into two brake lines. The CMakeLists now says so in a
    comment loud enough to survive a late-night rig swap.
    Rather than reimplement alignment for the bench, the sketch compiles the real
    domain objects — CornerEdgeDetector, DeadReckonOdometry, DockingStateMachine,
    SafetyMonitor — straight out of lib/domain and drives them with Vl53l0xArray on
    the XSHUT pins. What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
    [sketch_pcb.cpp]
2026-08-12 fix: start the I2C bus in bench_ble — the ToF had never worked there
    sketch_pcb.cpp never called Wire.begin(). Vl53l0xArray deliberately does not
    own the bus (it is shared with the IMU, the current-sense ADC and the encoder
    mux, so one place starts it and the rest join) and main.cpp had the call all
    along, but it was not carried over when the bench firmware was written. Every
    VL53L0X init() was therefore talking to an unconfigured peripheral, all four
    failed identically, and the single bool begin() returns made that look exactly
    like a wiring fault. With the line added, 4/4 come up on the assembled base.
    The diagnostics that found it, kept because the next fault will not be this one:
    *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
    [config.h, main.cpp, pins.h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]
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2026-08-14 fix: give the app 3 MB — WiFi pushed it past the 1 MB partition
    The ESP-NOW change took the binary from ~795 KB to 1.28 MB and the board would
    not boot at all:
    E esp_image: Image length 1309008 doesn't fit in partition length 1048576
    E boot: No bootable app partitions in the partition table
    Two separate things were wrong, and fixing either alone would not have helped.
    PLATFORMIO GENERATES THE PARTITION TABLE, NOT THE SDKCONFIG. sdkconfig.defaults
    has asked for CONFIG_PARTITION_TABLE_SINGLE_APP_LARGE since this project was
    created, and the generated sdkconfig duly recorded
    partitions_singleapp_large_coredump.csv (1500 K app). The flashed table was a
    1 MB single_app with no coredump p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
    [partitions.csv]
2026-08-14 feat: pin the arm firmware as a submodule, and fix the sender against it
    sks0826/Arm_code is now `arm/`, pinned at ca81eef. The base firmware sends four
    strings to a board whose source nobody on this side could read; that is how the
    UART flush bug went unnoticed for a week. Reviewing it turned up three things.
    THE COMMAND STRINGS ARE CORRECT AS SENT. "grab", "release", "home_setup",
    "estop", lowercase, NUL-terminated. Nothing to change there.
    THE BUSY MODEL WAS WRONG. It latched when the arm ANSWERED "busy" and cleared
    after one refusal, so every other press got through. The arm actually:
    * accepts exactly ONE command at a time -- its receive callback overwrites a
    single slot, so a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
    [sketch_pcb.cpp]
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2026-08-14 fix: filter ESP-NOW by sender — stray frames were clearing the busy interlock
    The receive callback discarded the sender address (`(void)info;`) and treated
    every frame on the channel as an arm reply. On the assembled robot that meant
    ~15 frames per second of binary from something else on channel 1, each printed
    as a garbled `arm -> "BV..."` line.
    The console noise was the harmless part. Every one of those frames also ran the
    terminal-reply test, and since none of them equalled "busy" they each CLEARED THE
    INTERLOCK. So the arm could be mid-workflow -- up to 40 seconds -- and the base
    would consider it idle and fire the next command into a single-slot receive
    buffer, where it would be sile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
    [sketch_pcb.cpp]
2026-08-14 fix: dedup ESP-NOW strangers properly — one slot could not hold two
    The single "last seen" cache was defeated by the actual environment: there are at
    least two other ESP-NOW devices broadcasting on channel 1 here
    (80:B5:4E:E3:E2:5C and F0:9E:9E:03:10:08, observed 2026-08-14). Alternating
    senders make every frame look new, so the log flooded exactly as it had before
    the filter was added -- with a different message.
    Now a four-entry seen-table, each stranger announced once ever, and a running
    count on the status line. If more than four ever appear the table stops learning
    and the counter carries the signal, which is the right failure mode: a busy
    channel should cost a number, not a scrollin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
    [sketch_pcb.cpp]
2026-08-14 fix: pace arm sends again — its mailbox holds ONE command, not a queue
    The jog sent "xret" and "mstop" back to back. The arm's receive callback
    overwrites pendingWirelessCommand unconditionally and loop() reads whatever is in
    the slot, so the pair collapsed to the stop and the motor never started.
    Measured on hardware: 30 sends, 2 replies. mstop always answers "stopped", so 28
    of them were never seen at all -- the arm got one message where two were sent,
    every time, and the jog looked dead while the console said it had been delivered.
    This is the same hazard the UART build had a queue for ("the arm reads ONE
    character then flushes the rest of the buffer"). That queue was removed when the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
    [sketch_pcb.cpp]
2026-08-14 feat: RT + D-pad flips the servo pairs
    RT + Up fx flip X pair out (170 -> 80)
    RT + Down ex X pair home (80 -> 170)
    RT + Right fy flip Y pair out
    RT + Left ey Y pair home
    Same axis mapping as the LT jog, so the D-pad means the same thing under either
    modifier. LT wins if both are held.
    PAIRS ONLY. The arm exposes fx/fy/ex/ey and nothing per-servo, so the four
    flippers cannot be driven individually without a change on that side.
    ONE SHOT PER PRESS, not held: each command is a complete 90 degree throw, and
    repeating it while the button is down re-issues a move the arm has already
    finished and ignores anyway (setXAxisFlipped returns early when already there).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
    [sketch_pcb.cpp]
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2026-08-15 docs: vendor the arm firmware and write down what the code cannot say
    Handover to SOAR. Three things a clone did not previously give you: the arm's
    firmware, the boards, and the reasons.
    ARM FIRMWARE, VENDORED — written by Kai Xiang and Heng Li, EPD Batch of 2028.
    From sks0826/Arm_code at ca81eef. It was a submodule until now, which is a poor
    fit for a handover: the three fixes it needs to talk to the base lived only in
    this working tree, so anyone cloning TrolleyBot got firmware that silently did
    not work with it. Vendoring makes one clone give one working pair of boards.
    arm/README.md carries the attribution, the four-command ESP-NOW interface the
    base depends on, and the fact that it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
    [Driver PCB-B_Cu.dxf, Driver PCB-B_Mask.dxf, Driver PCB-B_Paste.dxf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]
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2026-08-31 chore: delete the encoder, I2C-mux and Raspberry Pi 5 code
    All three were confirmed abandoned: no encoders, no mux, no Pi in the
    delivered machine. They were left in the tree compiling, which is the
    failure mode include/pins.h already warns about -- "a table describing
    hardware nobody drives is indistinguishable from one describing hardware
    somebody does". The same is true of 300-odd lines of code.
    Deleted outright:
    lib/hal_esp32/Vl53l0xMux.h no consumers at all
    src/bench_i2cmux.h, bench_tof4.h used only by sketch_bld.cpp
    bench_ble/main/sketch_bld.cpp breadboard rig, CMakeLists marked it
    DO NOT BUILD; sole consumer of the above
    tools/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
    [config.h, main.cpp, pcb_identify.cpp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]
2026-08-31 chore: delete the breadboard motor bench and the remaining mux paths
    Follow-up to the encoder/mux/Pi removal in this branch.
    Deleted:
    src/bench_s3_motor.cpp breadboard AS5600 motor-characterisation rig, and
    its [env:bench_s3] block. Its sibling breadboard
    sketch (sketch_bld.cpp) went earlier in this branch;
    without encoders it cannot do the job it existed for.
    Stripped, both tools keeping their purpose:
    src/tof_scan.cpp 162 -> 119 lines. The mux multi-sensor mode is gone; the
    single-sensor raw/median/corrected view stays, which is
    what TOF_SCALE and TOF_OFFSE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
    [i2c_scan.cpp, teleop.py, tof_scan.cpp]
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
